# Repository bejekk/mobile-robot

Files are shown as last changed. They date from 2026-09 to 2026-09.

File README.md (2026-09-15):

# Robot mobilny — praca inżynierska

Konstrukcja i oprogramowanie czterokołowego (gąsienicowego) robota mobilnego.
Firmware czasu rzeczywistego na **STM32H755**, sterowanie z **ROS 2 Humble** na Jetson Nano, płyta główna w **KiCad** oraz modele mechaniczne przekładni i obudowy.

Autor: **Błażej Kruszka**, Uniwersytet Mikołaja Kopernika w Toruniu, 2025–2026.

## Architektura

```
gamepad  →  ROS 2 (Jetson)  →  UART 115200  →  STM32H755
                 │                                  │
                 └── /telemetry ← prędkości PI ← enkodery DC, PWM, A4988
```

- **STM32 (CM7)** — enkodery, regulatory PI, mostki H (4× DC), silniki krokowe (4× A4988), protokół UART.
- **ROS 2** — odczyt pada, mostek szeregowy, logger telemetrii.
- **PCB** — płyta główna pod Nucleo-H755, 8 kanałów wykonawczych i interfejsy czujników.

## Struktura repozytorium

| Katalog | Zawartość |
| --- | --- |
| `firmware/` | Projekt STM32CubeIDE (dual-core STM32H755ZITX), bez artefaktów kompilacji |
| `ros2_ws/` | Pakiet `robot_control` + Dockerfile |
| `pcb/` | KiCad (schemat, PCB, Gerber) |
| `mechanical/` | Modele STL i archiwum Fusion 360 |
| `control/` | Skrypt MATLAB do identyfikacji regulatorów PI |
| `docs/` | Praca, prezentacja, opis protokołu UART |

Nie ma tu notatek roboczych, dumpów CubeIDE, kopii zapasowych KiCad, filmów ani cudzych prac.

## Firmware (STM32)

Otwórz folder `firmware/` w STM32CubeIDE (projekt dual-core nadal nazywa się `jakie_wyjscia` — tak zapisał CubeMX). Zbuduj konfigurację **CM7 Debug** oraz CM4, jeśli boot dual-core ma zostać zachowany.

Aplikacja użytkownika:

- `firmware/CM7/Core/Src/PI.c` — pomiar prędkości z enkodera, filtr i regulator PI z rampą oraz anti-windup
- `firmware/CM7/Core/Src/motor_control.c` — PWM + kierunek mostka H, sleep/dir silników krokowych
- `firmware/CM7/Core/Src/main.c` — parser UART, pętla 10 ms, telemetria

Po resecie STM32 czeka na komendę `ready` (buzzer), dopiero potem przyjmuje zadawanie prędkości i krokowych.

## ROS 2

Wymagania: ROS 2 Humble, `python3-serial`, pakiet `inputs`.

```bash
cd ros2_ws
source /opt/ros/humble/setup.bash
colcon build --symlink-install
source install/setup.bash
ros2 launch robot_control robot.launch.py
```

Port UART można zmienić parametrem węzła `stm_bridge`:

```bash
ros2 run robot_control stm_bridge --ros-args -p port:=/dev/ttyACM0 -p baudrate:=115200
```

### Docker (Jetson)

```bash
cd ros2_ws
sudo docker build -t robot_control:humble .
xhost +local:root
sudo docker run -it --rm --network host \
  --runtime nvidia \
  -e DISPLAY=$DISPLAY \
  -v /tmp/.X11-unix:/tmp/.X11-unix \
  --device /dev/input/js0 \
  --device /dev/ttyACM0 \
  robot_control:humble
```

W kontenerze: `source /home/ros_user/ws/install/setup.bash && ros2 launch robot_control robot.launch.py`.

## MATLAB

`control/pi_identification.m` wysyła sekwencję skoków `lspeed`/`rspeed` i rysuje zadanie vs. pomiar dla czterech kół. Ustaw `portName` na swój port (`COM18` w Windows, `/dev/ttyACM0` w Linux).

## PCB

Projekt KiCad 8: `pcb/PCBV2.kicad_pro`. Gerbery do produkcji są w `pcb/gerber/`. Podgląd schematu: `pcb/PCBV2.pdf`.

## Protokół UART

Zobacz [docs/uart.md](docs/uart.md).

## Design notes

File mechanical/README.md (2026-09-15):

# Modele mechaniczne

Eksporty z projektu obudowy i przekładni ślimakowej.

| Plik | Część |
| --- | --- |
| `korpus.stl` | Korpus |
| `pokrywa.stl` | Pokrywa |
| `obudowa.f3z` | Archiwum Fusion 360 |
| `slimak.stl` / `slimacznica.stl` | Przekładnia ślimakowa |
| `ramie.stl` | Ramię |
| `felga_opona.stl` / `felga_gasienica.stl` | Felgi |
| `laczenie_walu1.stl` / `laczenie_wal2.stl` | Łączniki wału |
| `uchwyt_krokowy.stl` | Uchwyt silnika krokowego |

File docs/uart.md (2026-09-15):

# Protokół UART (115200 8N1)

Linie kończy `\n`. STM32 zaczyna wykonywać komendy jezdne dopiero po `ready`.

## Komendy do STM32

| Komenda | Znaczenie |
| --- | --- |
| `ready` | Start pętli regulacji i krótki sygnał buzzera |
| `lspeed=<int>` | Zadana prędkość lewej burty, zakres ok. −100…100 (% max RPM) |
| `rspeed=<int>` | Zadana prędkość prawej burty |
| `forward` / `backward` / `stop` | Kierunek / zatrzymanie silników krokowych (aktywne tylko te, które włączono `*_step`) |
| `fright_step` / `fleft_step` / `bright_step` / `bleft_step` | Przełączenie danego silnika krokowego |
| `P=<int>` / `I=<int>` | Współczynniki PI dla wszystkich czterech kół DC |

## Telemetria ze STM32

CSV, 8 wartości, okres 100 ms:

```
rb_set, rb_meas, rf_set, rf_meas, lb_set, lb_meas, lf_set, lf_meas
```

Jednostka: RPM (zadanie i prędkość przefiltrowana z enkodera).
Mostek ROS dopina na końcu aktualne `lspeed` i `rspeed` wysłane z pada.

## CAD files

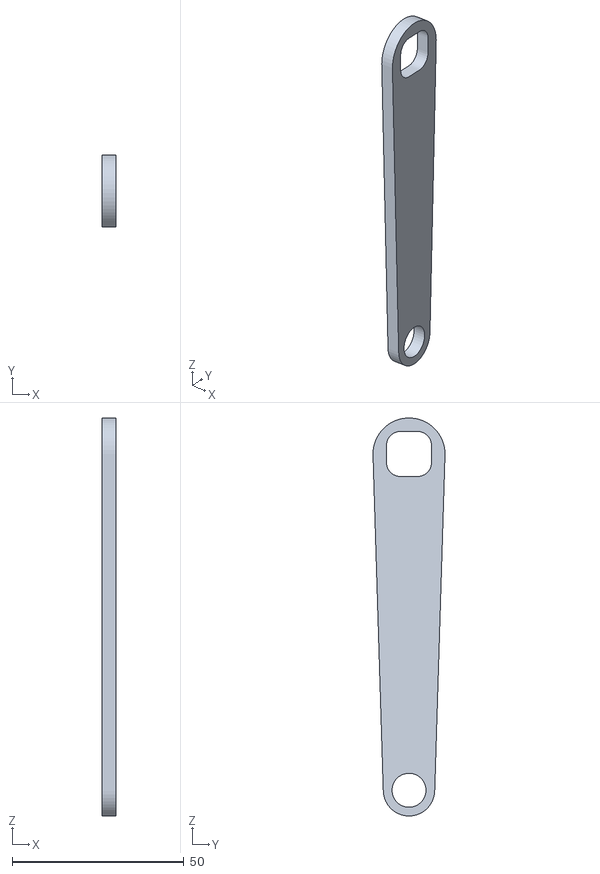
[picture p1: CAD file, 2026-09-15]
mechanical/ramie.stl
4.00 x 21.0 x 116.0

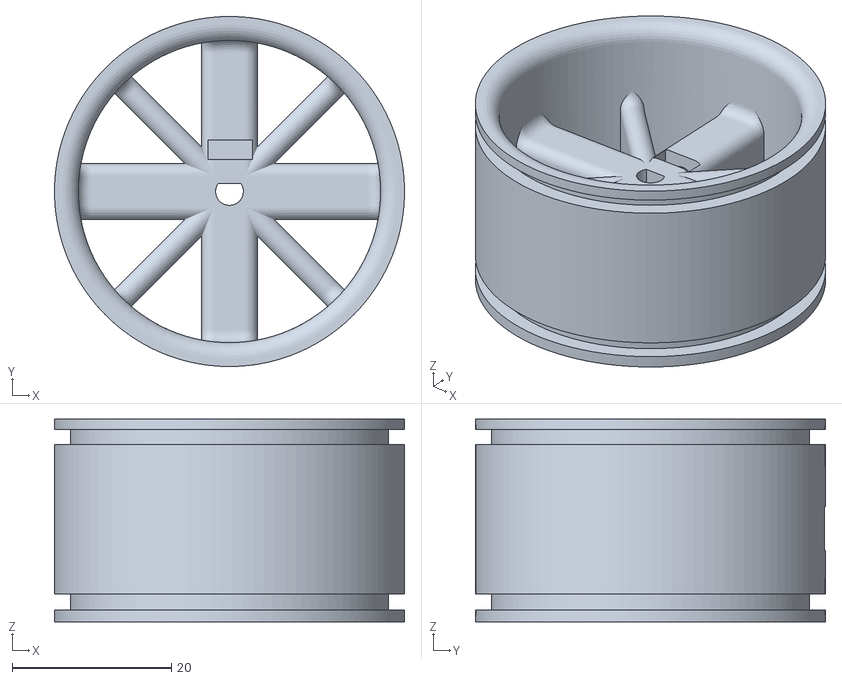
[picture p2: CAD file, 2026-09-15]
mechanical/felga_opona.stl
44.0 x 44.0 x 25.5

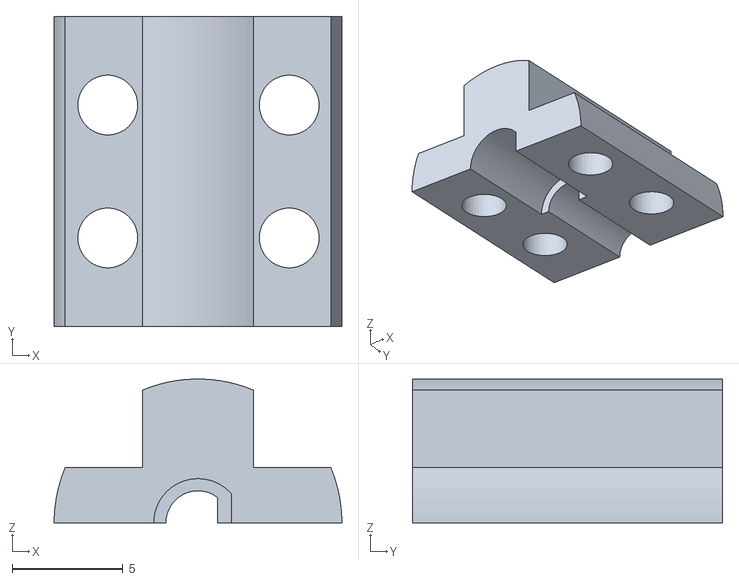
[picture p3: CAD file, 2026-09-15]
mechanical/laczenie_walu1.stl
13.0 x 14.0 x 6.50

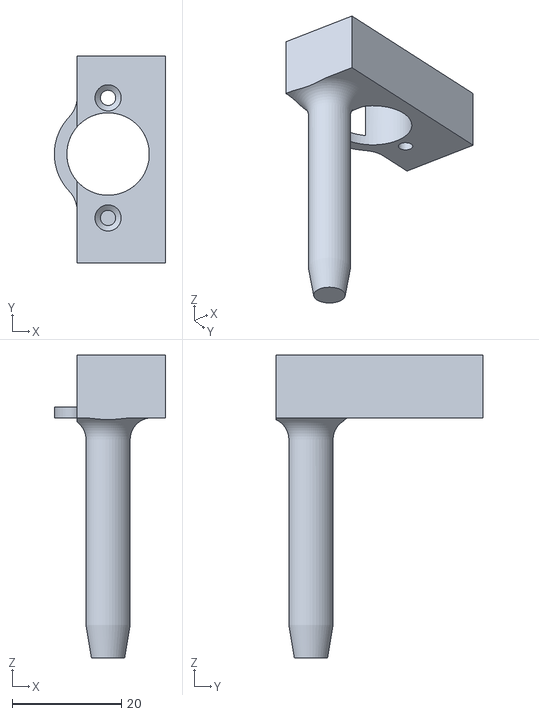
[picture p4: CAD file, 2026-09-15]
mechanical/uchwyt_krokowy.stl
20.4 x 38.0 x 55.5

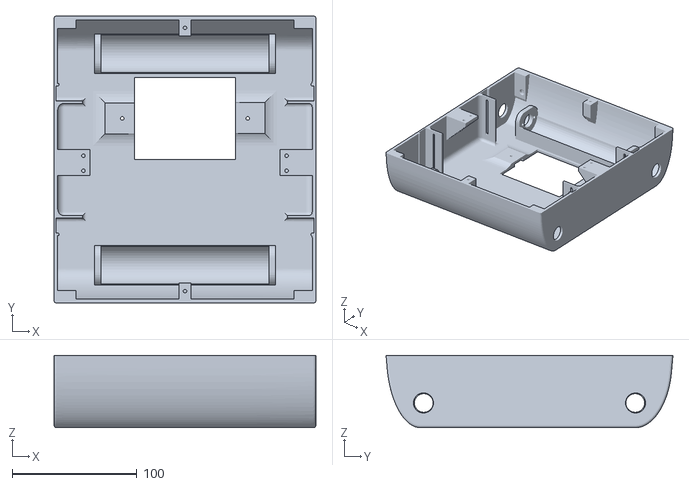
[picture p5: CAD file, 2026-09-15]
mechanical/korpus.stl
210.0 x 230.0 x 58.0

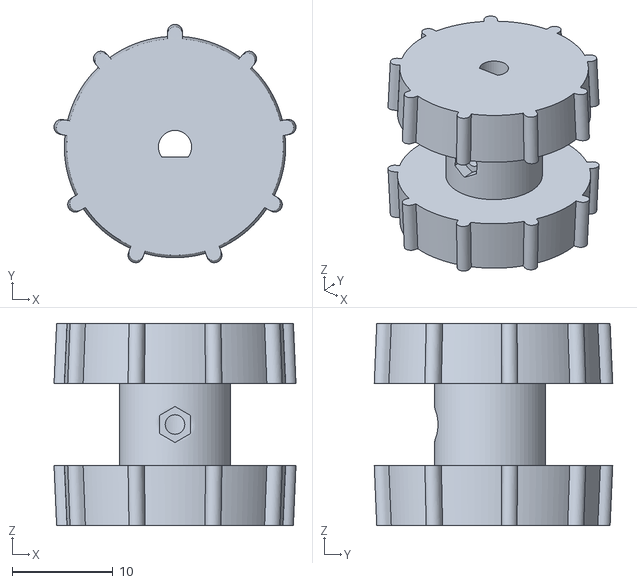
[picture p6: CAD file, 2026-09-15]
mechanical/felga_gasienica.stl
24.0 x 23.7 x 20.1

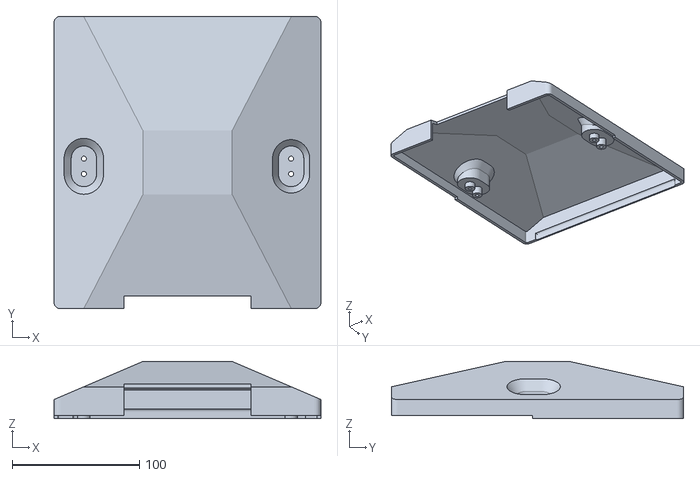
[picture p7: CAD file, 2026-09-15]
mechanical/pokrywa.stl
210.0 x 230.0 x 45.0

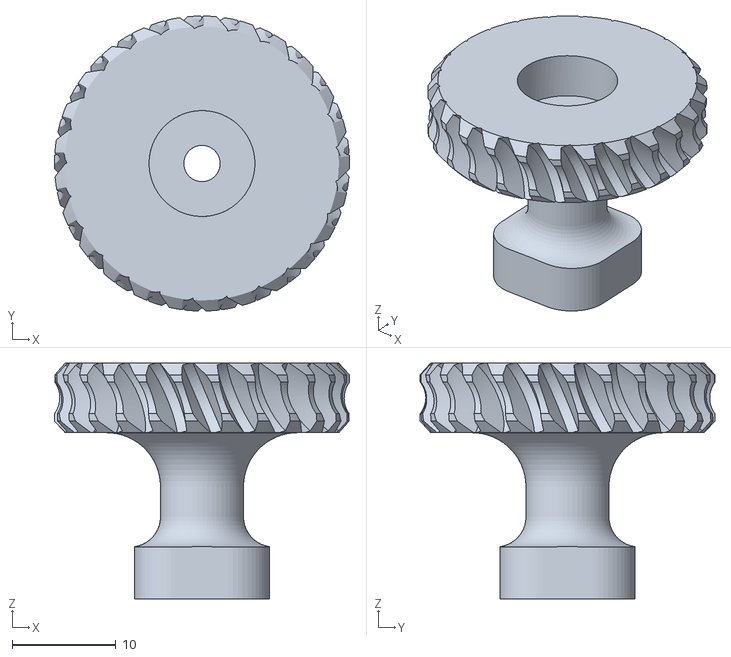
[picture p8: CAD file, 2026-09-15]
mechanical/slimacznica.stl
28.4 x 28.4 x 22.7

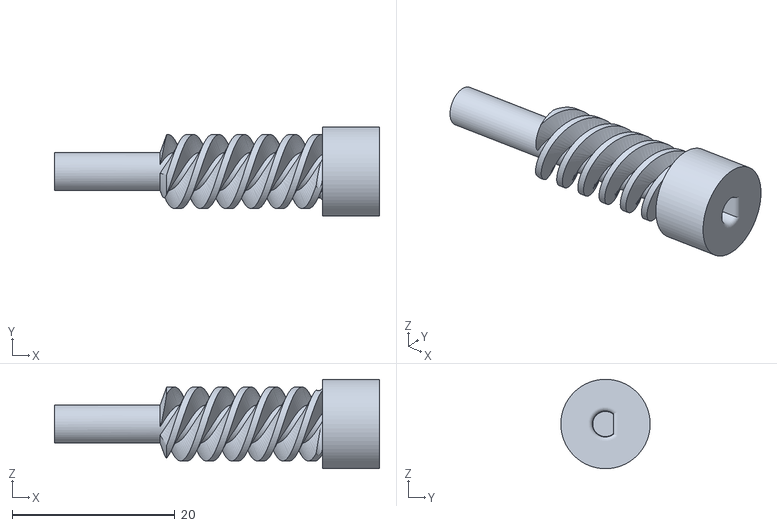
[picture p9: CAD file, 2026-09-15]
mechanical/slimak.stl
40.0 x 11.0 x 11.0

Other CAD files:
mechanical/laczenie_wal2.stl
mechanical/obudowa.f3z

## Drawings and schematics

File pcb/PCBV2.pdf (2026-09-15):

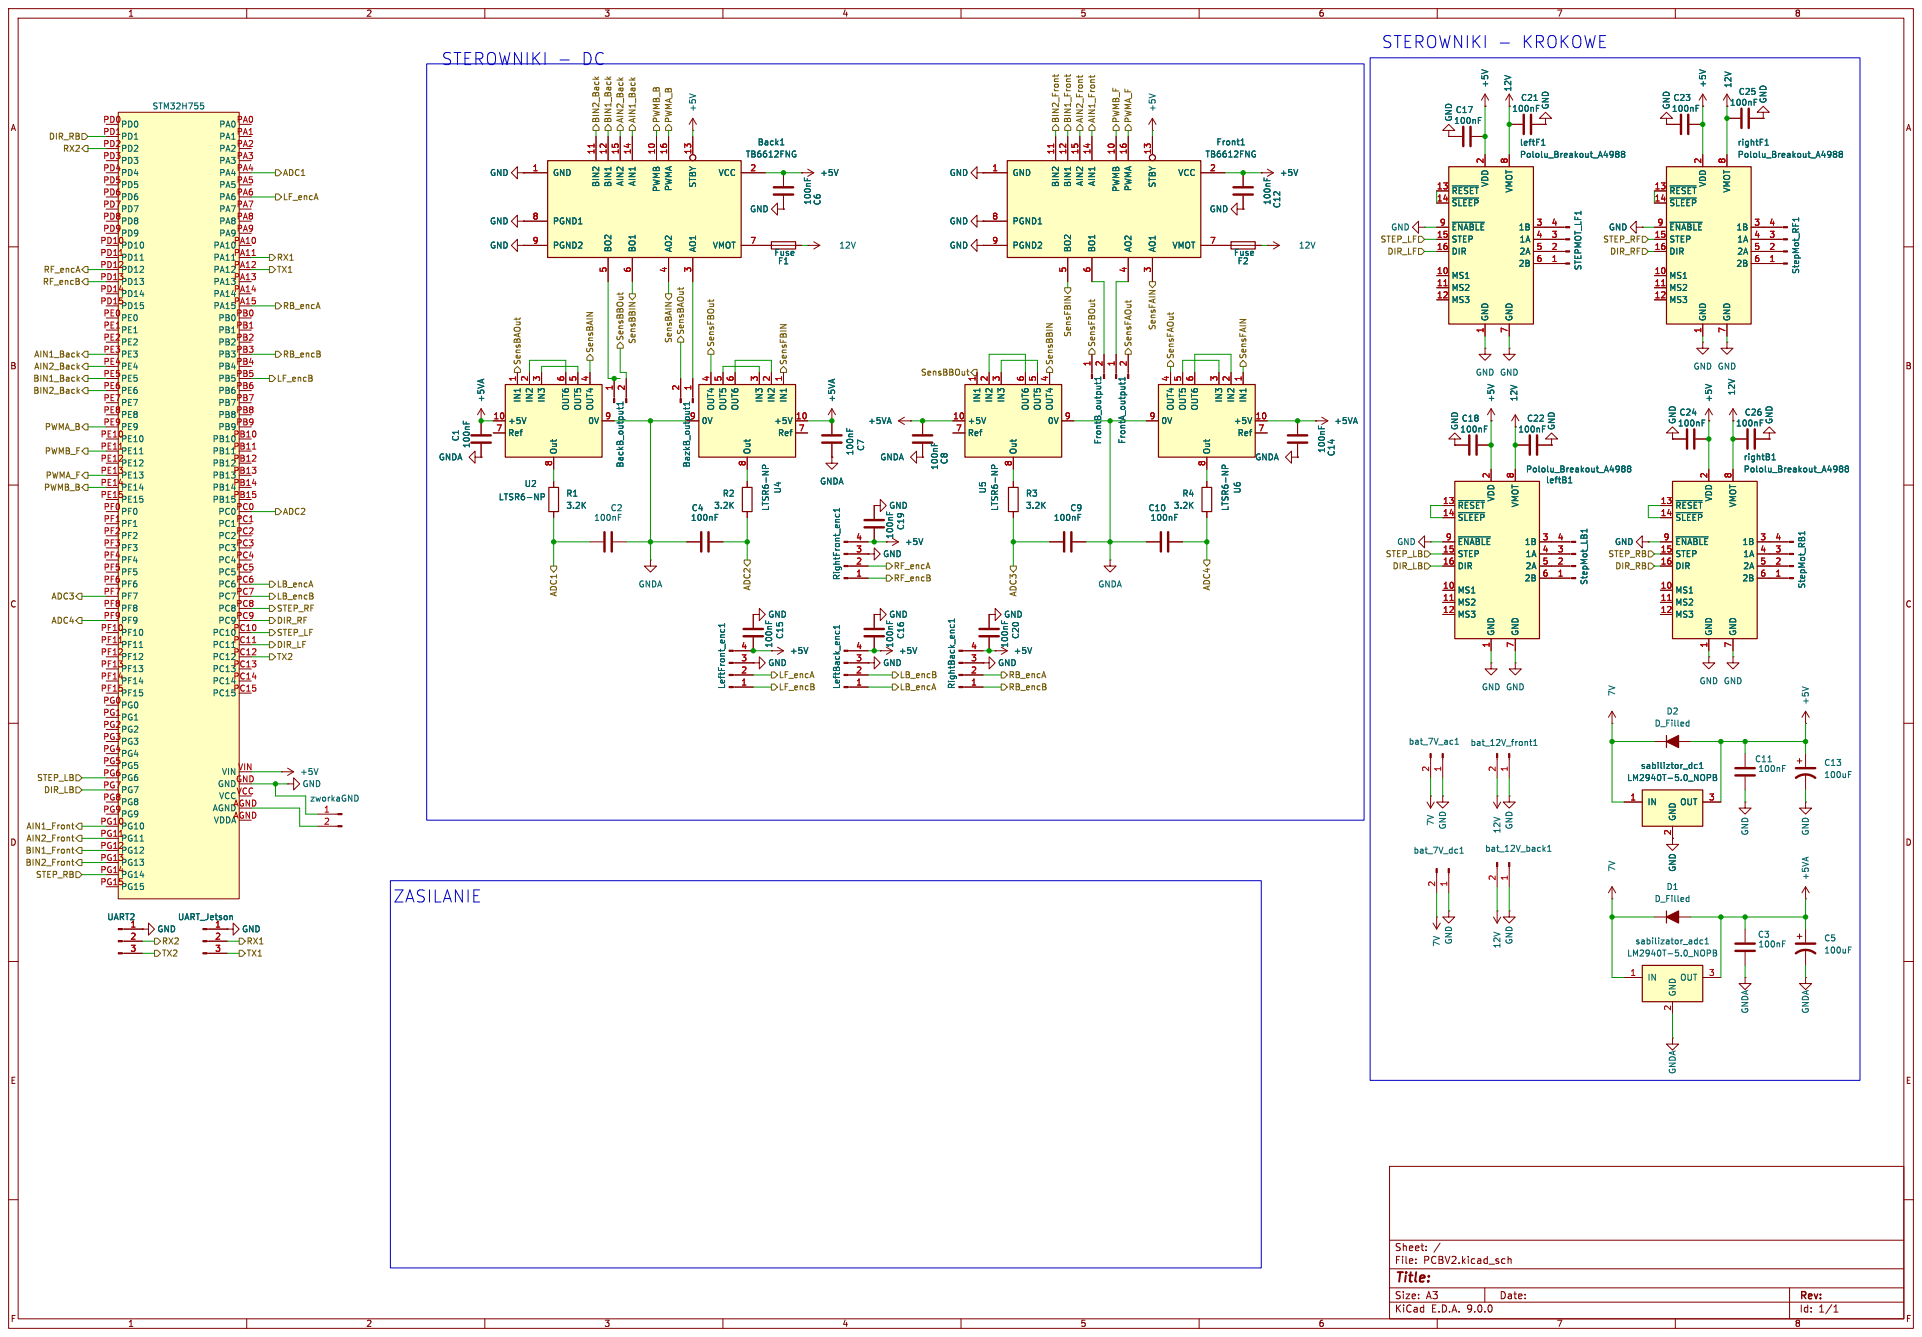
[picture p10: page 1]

4 +5V 10 0V 9 Ref 7 Out 8 Front1 TB6612FNG STBY 13 PWMA 16 PWMB 10 AIN1 14 AIN2 15 BIN1 12 BIN2 11 VCC 2 GND 1 PGND1 8 VMOT 7 PGND2 9 AO1

rightF1 Pololu_Breakout_A4988 ~{RESET} 13 ~{SLEEP} 14 ~{ENABLE} 9 STEP

rightF1 Pololu_Breakout_A4988
~{RESET} 13 ~{SLEEP} 14 ~{ENABLE} 9 STEP

GND GND

4 +5V 10 0V 9 Ref 7 Out 8 U4 LTSR6-NP 7V D2 D_Filled GND GND C7 100nF

rightB1 Pololu_Breakout_A4988 ~{RESET} 13 ~{SLEEP} 14 ~{ENABLE} 9 STEP

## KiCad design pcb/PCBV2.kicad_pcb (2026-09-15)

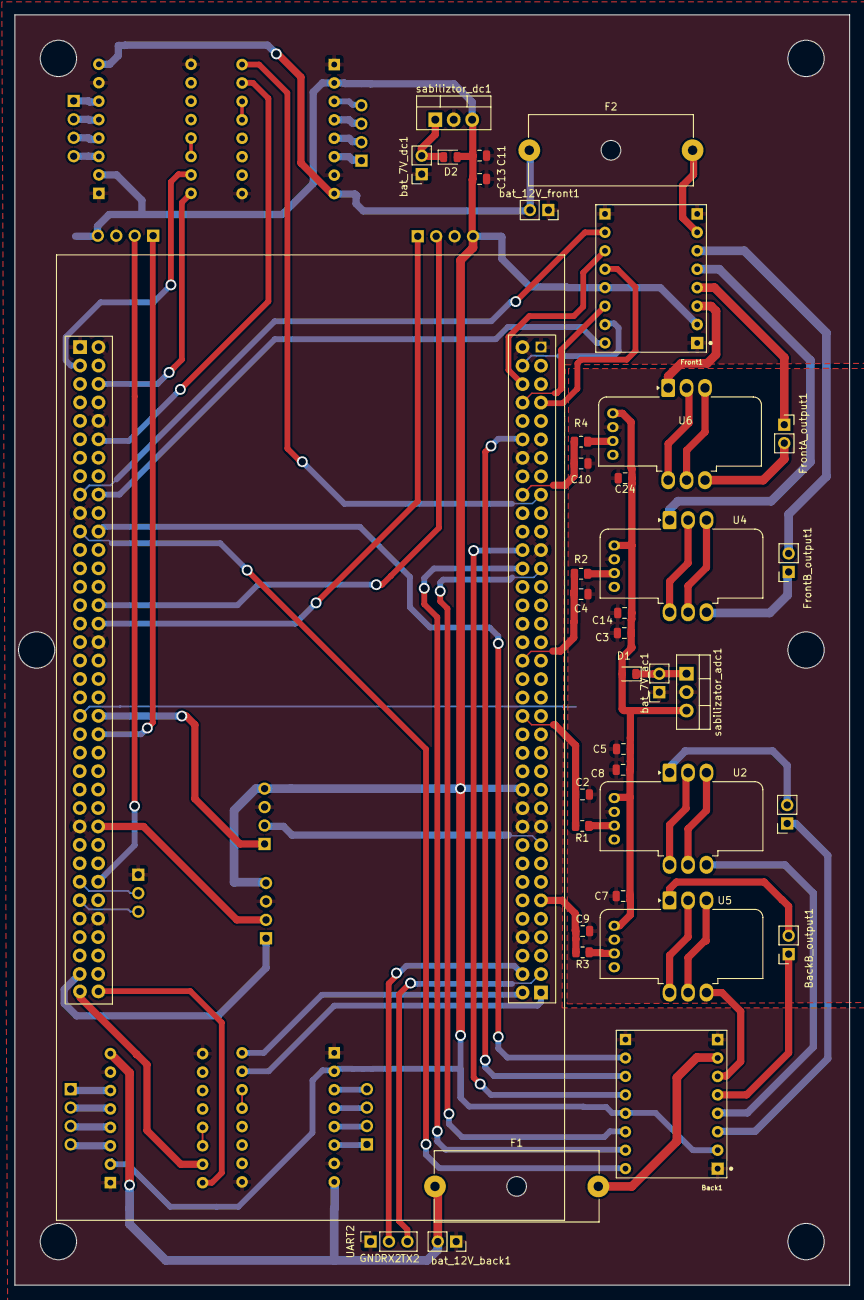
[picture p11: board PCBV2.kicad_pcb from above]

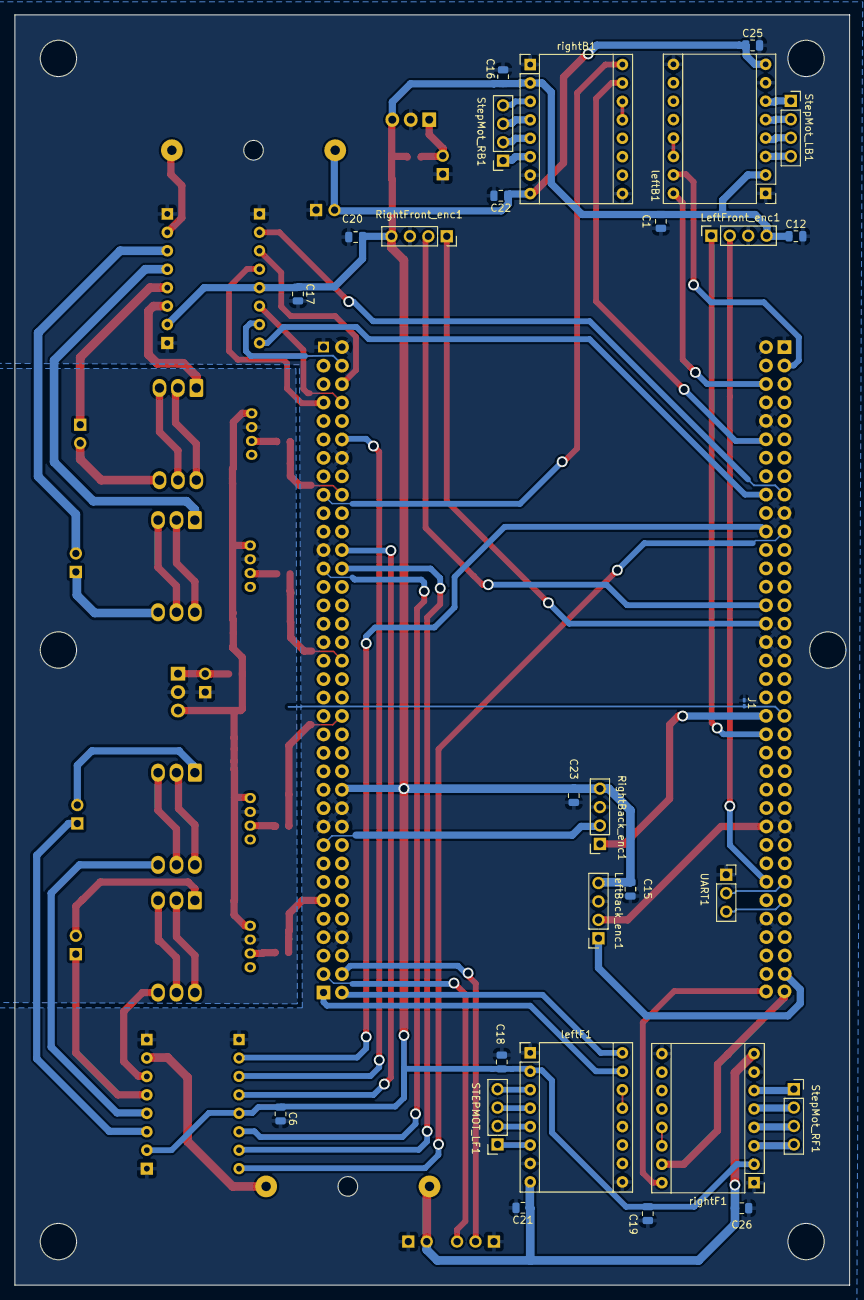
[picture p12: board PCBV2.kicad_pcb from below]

Board: 4 copper layers, 115.0 x 175.0 mm, 66 parts (28 on the bottom side), 89 nets.

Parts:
Back1: TB6612FNG; SHIELD_POLOLU-713
BackB_output1: PinSocket_1x02_P2.54mm_Vertical
BazkB_output1: PinSocket_1x02_P2.54mm_Vertical
C1, C2, C3, C4, C6, C7, C8, C9, C10, C11, C12, C14, C15, C16, C17, C18, C19, C20, C21, C22, C23, C24, C25, C26: 100nF; C_0805_2012Metric
C5, C13: 100uF; C_0805_2012Metric
D1, D2: D_Filled; D_0805_2012Metric
F1, F2: Fuse; Fuseholder_Cylinder-5x20mm_Schurter_0031_8201_Horizontal_Op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
Front1: TB6612FNG; SHIELD_POLOLU-713
FrontA_output1: PinSocket_1x02_P2.54mm_Vertical
FrontB_output1: PinSocket_1x02_P2.54mm_Vertical
J1: zworaGND; R_0201_0603Metric_Pad0.64x0.40mm_HandSolder
LeftBack_enc1: Conn_01x04_Pin; PinSocket_1x04_P2.54mm_Vertical
LeftFront_enc1: Conn_01x04_Pin; PinSocket_1x04_P2.54mm_Vertical
R1, R2, R3, R4: 3.2K; R_0805_2012Metric
RightBack_enc1: Conn_01x04_Pin; PinSocket_1x04_P2.54mm_Vertical
RightFront_enc1: Conn_01x04_Pin; PinSocket_1x04_P2.54mm_Vertical
STEPMOT_LF1: Conn_01x04_Pin; PinSocket_1x04_P2.54mm_Vertical
StepMot_LB1: Conn_01x04_Pin; PinSocket_1x04_P2.54mm_Vertical
StepMot_RB1: Conn_01x04_Pin; PinSocket_1x04_P2.54mm_Vertical
StepMot_RF1: Conn_01x04_Pin; PinSocket_1x04_P2.54mm_Vertical
U1: STM32H755
U2, U4, U5, U6: LTSR6-NP; LEM_LTSR-NP
UART1: UART1; PinSocket_1x03_P2.54mm_Vertical
UART2: UART2; PinSocket_1x03_P2.54mm_Vertical
bat_7V_ac1, bat_7V_dc1, bat_12V_back1, bat_12V_front1: PinSocket_1x02_P2.54mm_Vertical
leftB1: Pololu_Breakout_A4988; Pololu_Breakout-16_15.2x20.3mm
leftF1: Pololu_Breakout_A4988; Pololu_Breakout-16_15.2x20.3mm
rightB1: Pololu_Breakout_A4988; Pololu_Breakout-16_15.2x20.3mm
rightF1: Pololu_Breakout_A4988; Pololu_Breakout-16_15.2x20.3mm
sabilizator_adc1: LM2940T-5.0_NOPB; TO-220-3_Vertical
sabiliztor_dc1: LM2940T-5.0_NOPB; TO-220-3_Vertical

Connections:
7V: D1.1 (K), D2.1 (K), bat_7V_ac1.2, bat_7V_dc1.2, sabilizator_adc1.1 (IN), sabiliztor_dc1.1 (IN)
12V: C21.1, C22.1, C25.1, C26.1, F1.1, F2.1, bat_12V_back1.2, bat_12V_front1.2, leftB1.8 (VMOT), leftF1.8 (VMOT), rightB1.8 (VMOT), rightF1.8 (VMOT)
+5V: Back1.2 (VCC), Back1.13 (STBY), C1.1, C6.1, C11.2, C12.1, C13.1, C15.1, C16.1, C17.1, C18.1, C19.1, C20.1, C23.1, D2.2 (A), Front1.2 (VCC), Front1.13 (STBY), LeftBack_enc1.4, LeftFront_enc1.4, RightBack_enc1.4, RightFront_enc1.4, U1.VIN, leftB1.2 (VDD), leftF1.2 (VDD), rightB1.2 (VDD), rightF1.2 (VDD), sabiliztor_dc1.3 (OUT)
+5VA: C3.2, C5.1, C7.1, C8.1, C14.1, C24.1, D1.2 (A), U2.10 (+5V), U4.10 (+5V), U5.10 (+5V), U6.10 (+5V), sabilizator_adc1.3 (OUT)
/ADC1: C2.1, R1.2, U1.PA4
/ADC2: C4.2, R2.2, U1.PC0
/ADC3: C9.1, R3.2, U1.PF7
/ADC4: C10.2, R4.2, U1.PF9
/AIN1_Back: Back1.14 (AIN1), U1.PE3
/AIN1_Front: Front1.14 (AIN1), U1.PG10
/AIN2_Back: Back1.15 (AIN2), U1.PE4
/AIN2_Front: Front1.15 (AIN2), U1.PG11
/BIN1_Back: Back1.12 (BIN1), U1.PE5
/BIN1_Front: Front1.12 (BIN1), U1.PG12
/BIN2_Back: Back1.11 (BIN2), U1.PE6
/BIN2_Front: Front1.11 (BIN2), U1.PG13
/DIR_LB: U1.PG7, leftB1.16 (DIR)
/DIR_LF: U1.PC11, leftF1.16 (DIR)
/DIR_RB: U1.PD1, rightB1.16 (DIR)
/DIR_RF: U1.PC9, rightF1.16 (DIR)
/LB_encA: LeftBack_enc1.1, U1.PC6
/LB_encB: LeftBack_enc1.2, U1.PC7
/LF_encA: LeftFront_enc1.2, U1.PA6
/LF_encB: LeftFront_enc1.1, U1.PB5
/PWMA_B: Back1.16 (PWMA), U1.PE9
/PWMA_F: Front1.16 (PWMA), U1.PE13
/PWMB_B: Back1.10 (PWMB), U1.PE14
/PWMB_F: Front1.10 (PWMB), U1.PE11
/RB_encA: RightBack_enc1.2, U1.PA15
/RB_encB: RightBack_enc1.1, U1.PB3
/RF_encA: RightFront_enc1.2, U1.PD12
/RF_encB: RightFront_enc1.1, U1.PD13
/RX1: U1.PA11, UART1.2
/RX2: U1.PD2, UART2.2
/STEP_LB: U1.PG6, leftB1.15 (STEP)
/STEP_LF: U1.PC10, leftF1.15 (STEP)
/STEP_RB: U1.PG14, rightB1.15 (STEP)
/STEP_RF: U1.PC8, rightF1.15 (STEP)
/SensBAIN: Back1.4 (AO2), U2.4 (OUT4)
/SensBAOut: BazkB_output1.2, U2.1 (IN1)
/SensBBIN: Back1.6 (BO1), U5.4 (OUT4)
/SensBBOut: BackB_output1.2, U5.1 (IN1)
/SensFAIN: Front1.3 (AO1), U6.1 (IN1)
/SensFAOut: FrontA_output1.2, U6.4 (OUT4)
/SensFBIN: Front1.5 (BO2), U4.1 (IN1)
/SensFBOut: FrontB_output1.1, U4.4 (OUT4)
/TX1: U1.PA12, UART1.3
/TX2: U1.PC12, UART2.3
GND: Back1.1 (GND), Back1.8 (PGND1), Back1.9 (PGND2), C1.2, C6.2, C11.1, C12.2, C13.2, C15.2, C16.2, C17.2, C18.2, C19.2, C20.2, C21.2, C22.2, C23.2, C25.2, C26.2, Front1.1 (GND), Front1.8 (PGND1), Front1.9 (PGND2), J1.1, LeftBack_enc1.3, LeftFront_enc1.3, RightBack_enc1.3, RightFront_enc1.3, U1.GND, UART1.1, UART2.1, bat_7V_dc1.1, bat_12V_back1.1, bat_12V_front1.1, leftB1.1 (GND), leftB1.7 (GND), leftB1.9 (~ENABLE), leftF1.1 (GND), leftF1.7 (GND), leftF1.9 (~ENABLE), rightB1.1 (GND), rightB1.7 (GND), rightB1.9 (~ENABLE), rightF1.1 (GND), rightF1.7 (GND), rightF1.9 (~ENABLE), sabiliztor_dc1.2 (GND)
GNDA: C2.2, C3.1, C4.1, C5.2, C7.2, C8.2, C9.2, C10.1, C14.2, C24.2, U2.9 (0V), U4.9 (0V), U5.9 (0V), U6.9 (0V), bat_7V_ac1.1, sabilizator_adc1.2 (GND)
unnamed: Back1.3 (AO1), BazkB_output1.1
unnamed: Back1.5 (BO2), BackB_output1.1
unnamed: Back1.7 (VMOT), F1.2
unnamed: Front1.4 (AO2), FrontA_output1.1
unnamed: Front1.6 (BO1), FrontB_output1.2
unnamed: F2.2, Front1.7 (VMOT)
unnamed: J1.2, U1.AGND
unnamed: STEPMOT_LF1.1, leftF1.6 (2B)
unnamed: STEPMOT_LF1.2, leftF1.5 (2A)
unnamed: STEPMOT_LF1.3, leftF1.4 (1A)
unnamed: STEPMOT_LF1.4, leftF1.3 (1B)
unnamed: StepMot_LB1.1, leftB1.6 (2B)
unnamed: StepMot_LB1.2, leftB1.5 (2A)
unnamed: StepMot_LB1.3, leftB1.4 (1A)
unnamed: StepMot_LB1.4, leftB1.3 (1B)
unnamed: StepMot_RB1.1, rightB1.6 (2B)
unnamed: StepMot_RB1.2, rightB1.5 (2A)
unnamed: StepMot_RB1.3, rightB1.4 (1A)
unnamed: StepMot_RB1.4, rightB1.3 (1B)
unnamed: StepMot_RF1.1, rightF1.6 (2B)
unnamed: StepMot_RF1.2, rightF1.5 (2A)
unnamed: StepMot_RF1.3, rightF1.4 (1A)
unnamed: StepMot_RF1.4, rightF1.3 (1B)
unnamed: U2.2 (IN2), U2.6 (OUT6)
unnamed: U2.3 (IN3), U2.5 (OUT5)
unnamed: R1.1, U2.8 (Out)
unnamed: U4.2 (IN2), U4.6 (OUT6)
unnamed: U4.3 (IN3), U4.5 (OUT5)
unnamed: R2.1, U4.8 (Out)
unnamed: U5.2 (IN2), U5.6 (OUT6)
unnamed: U5.3 (IN3), U5.5 (OUT5)
unnamed: R3.1, U5.8 (Out)
unnamed: U6.2 (IN2), U6.6 (OUT6)
unnamed: U6.3 (IN3), U6.5 (OUT5)
unnamed: R4.1, U6.8 (Out)
unnamed: leftB1.13 (~RESET), leftB1.14 (~SLEEP)
unnamed: leftF1.13 (~RESET), leftF1.14 (~SLEEP)
unnamed: rightB1.13 (~RESET), rightB1.14 (~SLEEP)
unnamed: rightF1.13 (~RESET), rightF1.14 (~SLEEP)

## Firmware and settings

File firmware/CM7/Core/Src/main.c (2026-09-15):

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
/* Includes ------------------------------------------------------------------*/
#include "main.h"
#include "lwip.h"

/* USER CODE BEGIN Includes */
#include "motor_control.h"
#include "PI.h"
#include <stdbool.h>
#include <stdio.h>
#include <string.h>
#include <math.h>
/* USER CODE END Includes */

/* USER CODE BEGIN PD */

#ifndef HSEM_ID_0
#define HSEM_ID_0 (0U) /* HW semaphore 0*/
#endif

/* USER CODE END PD */

ADC_HandleTypeDef hadc1;
ADC_HandleTypeDef hadc3;

I2C_HandleTypeDef hi2c1;

SPI_HandleTypeDef hspi1;

TIM_HandleTypeDef htim1;
TIM_HandleTypeDef htim2;
TIM_HandleTypeDef htim3;
TIM_HandleTypeDef htim4;
TIM_HandleTypeDef htim6;
TIM_HandleTypeDef htim7;
TIM_HandleTypeDef htim8;
TIM_HandleTypeDef htim13;
TIM_HandleTypeDef htim14;
TIM_HandleTypeDef htim15;

UART_HandleTypeDef huart4;
UART_HandleTypeDef huart5;
UART_HandleTypeDef huart7;
UART_HandleTypeDef huart3;

/* USER CODE BEGIN PV */
uint8_t rx_byte;		/* bajt z USART3 (przerwanie RX) */
char rx_buffer[50];		/* składana komenda UART aż do '\n' */
uint8_t rx_index = 0;

/* Flagi silników krokowych (1 = dany A4988 ma być aktywny przy forward/backward). */
volatile uint8_t fright = 0, fleft = 0, bright = 0, bleft = 0, stop = 0, forward = 0, backward = 0;
volatile int Rvel = 0, Lvel = 0;	/* zadanie z UART: lspeed/rspeed w % */
volatile uint16_t steps_fright = 0, steps_bright = 0, steps_fleft = 0, steps_bleft = 0;

DC_str right_front, left_front, right_back, left_back;

int Kp = 14;
int Ki = 30;
int32_t MAX_SPEED_RPM = 200;

float P = 0;
volatile uint32_t raw_adc_val1 = 0;
volatile uint32_t raw_adc_val3 = 0;
volatile float PomiarADC;	/* prąd z przetwornika LTS (skalowanie w pętli głównej) */

/* USER CODE END PV */

void SystemClock_Config(void);
void PeriphCommonClock_Config(void);
static void MPU_Config(void);
static void MX_GPIO_Init(void);
static void MX_ADC1_Init(void);
static void MX_ADC3_Init(void);
static void MX_SPI1_Init(void);
static void MX_TIM1_Init(void);
static void MX_TIM2_Init(void);
static void MX_TIM3_Init(void);
static void MX_TIM4_Init(void);
static void MX_TIM8_Init(void);
static void MX_UART4_Init(void);
static void MX_TIM6_Init(void);
static void MX_TIM7_Init(void);
static void MX_UART7_Init(void);
static void MX_I2C1_Init(void);
static void MX_TIM13_Init(void);
static void MX_TIM14_Init(void);
static void MX_UART5_Init(void);
static void MX_USART3_UART_Init(void);
static void MX_TIM15_Init(void);
/* USER CODE BEGIN 0 */
void DC_str_init(DC_str *m, TIM_HandleTypeDef *tim, int8_t d, int32_t max)
{
	m->timer = tim;
	m->pulse_count = 0;
	m->actual_speed = 0;
	m->d = d;			/* znak enkodera — lewa/prawa oś mogą być lustrzane */
	m->max_speed = max;
	m->target_speed = 0;
	m->error_sum = 0;
	m->last_output = 0;
	m->current_setpoint = 0.0f;
	m->alpha = 0.1f;		/* silne wygładzenie na starcie */
	m->filtered_speed = 0.0f;
}

/* Telemetria: zadanie i pomiar [RPM] dla 4 kół, kolejność RB, RF, LB, LF. */
void UART_SendSpeeds(void)
{
	char msg[100];
	int len = sprintf(msg, "%ld, %ld, %ld, %ld, %ld, %ld, %ld, %ld\r\n",
			  (long)right_back.target_speed,
			  (long)right_back.filtered_speed,
			  (long)right_front.target_speed,
			  (long)right_front.filtered_speed,
			  (long)left_back.target_speed,
			  (long)left_back.filtered_speed,
			  (long)left_front.target_speed,
			  (long)left_front.filtered_speed);
	HAL_UART_Transmit(&huart3, (uint8_t *)msg, len, 10);	/* UART3 → Jetson / PC */
}

static int buzzer_tick = 0;

void HAL_TIM_PeriodElapsedCallback(TIM_HandleTypeDef *htim)
{
	/* TIM13: pętla 10 ms — buzzer po "ready", PI i PWM kół DC. */
	if (htim->Instance == TIM13) {
		/* Krótki impuls buzzera (~0,5 s) po starcie pętli regulacji. */
		if (buzzer_tick < 50) {
			HAL_GPIO_WritePin(GPIOD, GPIO_PIN_6, GPIO_PIN_SET);
			buzzer_tick++;
		} else if (buzzer_tick < 60) {
			HAL_GPIO_WritePin(GPIOD, GPIO_PIN_6, GPIO_PIN_RESET);
			buzzer_tick = 100;
		}

		DC_update_speed(&right_front);
		DC_update_speed(&left_front);
		DC_update_speed(&right_back);
		DC_update_speed(&left_back);

		static uint8_t uart_div = 0;
		if (++uart_div >= 10) {		/* 10 × 10 ms = 100 ms telemetrii */
			UART_SendSpeeds();
			uart_div = 0;
		}

		int16_t out_rf = PI_Compute(&right_front);
		int16_t out_rb = PI_Compute(&right_back);
		int16_t out_lf = PI_Compute(&left_front);
		int16_t out_lb = PI_Compute(&left_back);

		/* Skalowanie wyjścia PI do zakresu PWM mostka (0…100). */
		fright_motor(((float)out_rf / right_front.max_speed) * 100);
		bright_motor(((float)out_rb / right_back.max_speed) * 100);
		fleft_motor(((float)out_lf / left_front.max_speed) * 100);
		bleft_motor(((float)out_lb / left_back.max_speed) * 100);
	}

	/* TIM6/7/14/15: impuls STEP na A4988 + zliczanie kroków. */
	if (htim->Instance == TIM6) {
		HAL_GPIO_TogglePin(GPIOG, GPIO_PIN_6);
		if (forward) {
			steps_bleft++;
		} else {
			steps_bleft--;
		}
	}
	if (htim->Instance == TIM7) {
		HAL_GPIO_TogglePin(GPIOG, GPIO_PIN_14);
		if (forward) {
			steps_bright++;
		} else {
			steps_bright--;
		}
	}
	if (htim->Instance == TIM15) {
		HAL_GPIO_TogglePin(GPIOC, GPIO_PIN_8);
		if (forward) {
			steps_fright++;
		} else {
			steps_fright--;
		}
	}
	if (htim->Instance == TIM14) {
		HAL_GPIO_TogglePin(GPIOC, GPIO_PIN_10);
		if (forward) {
			steps_fleft++;
		} else {
			steps_fleft--;
		}
	}
}

void parse_command(char command[50])
{
	static bool ready = false;

	/* Bez "ready" pętla PI nie startuje — zabezpieczenie przed jazdą tuż po resecie USB. */
	if (strcmp(command, "ready") == 0) {
		HAL_TIM_Base_Start_IT(&htim13);
		ready = true;
	}

	if (ready) {
		/* *_step przełącza, czy dany silnik krokowy ma jechać przy forward/backward. */
		if (strcmp(command, "fright_step") == 0) {
			fright = !fright;
		} else if (strcmp(command, "fleft_step") == 0) {
			fleft = !fleft;
		} else if (strcmp(command, "bleft_step") == 0) {
			bleft = !bleft;
		} else if (strcmp(command, "bright_step") == 0) {
			bright = !bright;
		}

		if (strcmp(command, "forward") == 0) {
			stepper_control(bleft, GPIOG, GPIO_PIN_7, 1, &htim6, GPIOG, GPIO_PIN_8);
			stepper_control(bright, GPIOD, GPIO_PIN_1, 1, &htim7, GPIOD, GPIO_PIN_10);
			stepper_control(fright, GPIOC, GPIO_PIN_9, 1, &htim15, GPIOB, GPIO_PIN_8);
			stepper_control(fleft, GPIOC, GPIO_PIN_11, 1, &htim14, GPIOB, GPIO_PIN_9);
		} else if (strcmp(command, "backward") == 0) {
			stepper_control(bleft, GPIOG, GPIO_PIN_7, 0, &htim6, GPIOG, GPIO_PIN_8);
			stepper_control(bright, GPIOD, GPIO_PIN_1, 0, &htim7, GPIOD, GPIO_PIN_10);
			stepper_control(fright, GPIOC, GPIO_PIN_9, 0, &htim15, GPIOB, GPIO_PIN_8);
			stepper_control(fleft, GPIOC, GPIO_PIN_11, 0, &htim14, GPIOB, GPIO_PIN_9);
		} else if (strcmp(command, "stop") == 0) {
			stepper_control(0, GPIOG, GPIO_PIN_7, 0, &htim6, GPIOG, GPIO_PIN_8);
			stepper_control(0, GPIOD, GPIO_PIN_1, 0, &htim7, GPIOD, GPIO_PIN_10);
			stepper_control(0, GPIOC, GPIO_PIN_9, 0, &htim15, GPIOB, GPIO_PIN_8);
			stepper_control(0, GPIOC, GPIO_PIN_11, 0, &htim14, GPIOB, GPIO_PIN_9);
		}

		/* lspeed/rspeed w % max RPM, ta sama wartość na koła przednie i tylne danej burty. */
		if (strncmp(command, "lspeed=", 7) == 0) {
			if (sscanf(command, "lspeed=%d", &Lvel) == 1) {
				left_front.target_speed = (left_front.max_speed / 100) * Lvel;
				left_back.target_speed = (left_back.max_speed / 100) * Lvel;
			}
		}
		if (strncmp(command, "rspeed=", 7) == 0) {
			if (sscanf(command, "rspeed=%d", &Rvel) == 1) {
				right_front.target_speed = (right_front.max_speed / 100) * Rvel;
				right_back.target_speed = (right_back.max_speed / 100) * Rvel;
			}
		}
	}

	/* P= i I= działają też przed ready — wygodne przy strojeniu z MATLABa. */
	if (strncmp(command, "P=", 2) == 0) {
		if (sscanf(command, "P=%d", &Kp) == 1) {
			right_front.Kp = (float)Kp;
			left_front.Kp = (float)Kp;
			right_back.Kp = (float)Kp;
			left_back.Kp = (float)Kp;
		}
	}
	if (strncmp(command, "I=", 2) == 0) {
		if (sscanf(command, "I=%d", &Ki) == 1) {
			right_front.Ki = (float)Ki;
			left_front.Ki = (float)Ki;
			right_back.Ki = (float)Ki;
			left_back.Ki = (float)Ki;
		}
	}
}

/* USER CODE END 0 */



/**
  * @brief  The application entry point.
  * @retval int
  */
int main(void)
{

/* USER CODE BEGIN Boot_Mode_Sequence_0 */
  int32_t timeout;
/* USER CODE END Boot_Mode_Sequence_0 */

  /* MPU Configuration--------------------------------------------------------*/
  MPU_Config();

/* USER CODE BEGIN Boot_Mode_Sequence_1 */
  /* Wait until CPU2 boots and enters in stop mode or timeout*/

/* USER CODE END Boot_Mode_Sequence_1 */
  /* MCU Configuration--------------------------------------------------------*/

  /* Reset of all peripherals, Initializes the Flash interface and the Systick. */
  HAL_Init();

  /* Configure the system clock */
  SystemClock_Config();

  /* Configure the peripherals common clocks */
  PeriphCommonClock_Config();
/* USER CODE BEGIN Boot_Mode_Sequence_2 */
/* When system initialization is finished, Cortex-M7 will release Cortex-M4 by means of
HSEM notification */
/*HW semaphore Clock enable*/
__HAL_RCC_HSEM_CLK_ENABLE();
/*Take HSEM */
HAL_HSEM_FastTake(HSEM_ID_0);
/*Release HSEM in order to notify the CPU2(CM4)*/
HAL_HSEM_Release(HSEM_ID_0,0);
/* wait until CPU2 wakes up from stop mode */
timeout = 0xFFFF;
while((__HAL_RCC_GET_FLAG(RCC_FLAG_D2CKRDY) == RESET) && (timeout-- > 0));
if ( timeout < 0 )
{
Error_Handler();
}
/* USER CODE END Boot_Mode_Sequence_2 */

  /* Initialize all configured peripherals */
  MX_GPIO_Init();
  MX_ADC1_Init();
  MX_ADC3_Init();
  MX_SPI1_Init();
  MX_TIM1_Init();
  MX_TIM2_Init();
  MX_TIM3_Init();
  MX_TIM4_Init();
  MX_TIM8_Init();
  MX_UART4_Init();
  MX_LWIP_Init();
  MX_TIM6_Init();
  MX_TIM7_Init();
  MX_UART7_Init();
  MX_I2C1_Init();
  MX_TIM13_Init();
  MX_TIM14_Init();
  MX_UART5_Init();
  MX_USART3_UART_Init();
  MX_TIM15_Init();
  /* USER CODE BEGIN 2 */
  /* Osobne Kp/Ki na koło — wartości z identyfikacji (MATLAB). */
  right_front.Kp = 13; right_front.Ki =15;
  left_front.Kp  = 12; left_front.Ki = 16;
  right_back.Kp  = 10; right_back.Ki = 17;
  left_back.Kp   = 12; left_back.Ki = 16;

  /* d = -1 tam, gdzie enkoder liczy w przeciwną stronę niż zadany ruch. */
  DC_str_init(&right_front, &htim3, -1, 350);
  DC_str_init(&left_front, &htim8, -1, 350);
  DC_str_init(&right_back, &htim4, -1, 350);
  DC_str_init(&left_back, &htim2, 1, 350);

  HAL_TIM_Encoder_Start(&htim2, TIM_CHANNEL_ALL);
  HAL_TIM_Encoder_Start(&htim3, TIM_CHANNEL_ALL);
  HAL_TIM_Encoder_Start(&htim4, TIM_CHANNEL_ALL);
  HAL_TIM_Encoder_Start(&htim8, TIM_CHANNEL_ALL);

  HAL_ADCEx_Calibration_Start(&hadc1, ADC_CALIB_OFFSET, ADC_SINGLE_ENDED);
  HAL_ADCEx_Calibration_Start(&hadc3, ADC_CALIB_OFFSET, ADC_SINGLE_ENDED);

  HAL_ADC_Start(&hadc1);
  HAL_UART_Receive_IT(&huart3, &rx_byte, 1);	/* start odbioru komend z ROS */
  /* USER CODE END 2 */

  /* Infinite loop */
  /* USER CODE BEGIN WHILE */
  while (1)
  {
	  if (HAL_ADC_PollForConversion(&hadc1, 10) == HAL_OK) {
	  							/* LTS-6-NP: 16-bit ADC → prąd [A] (2 / 0.625 ze wzmocnienia). */
	  							PomiarADC = ((float)HAL_ADC_GetValue(&hadc1)/65536*3.3)*2/0.625;
	  							HAL_ADC_Start(&hadc1);
	  						}
    /* USER CODE END WHILE */

    /* USER CODE BEGIN 3 */
  }
  /* USER CODE END 3 */
}

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
/* USER CODE BEGIN 4 */
void HAL_UART_RxCpltCallback(UART_HandleTypeDef *huart)
{
	if (huart->Instance == USART3) {
		if (rx_byte == '\n' || rx_byte == '\r') {
			rx_buffer[rx_index] = 0;	/* zakończ string */
			parse_command(rx_buffer);
			rx_index = 0;
		} else if (rx_index < 49) {	/* ochrona przed przepełnieniem bufora */
			rx_buffer[rx_index++] = rx_byte;
		}
		/* RX IT trzeba zbroić ponownie po każdym bajcie. */
		HAL_UART_Receive_IT(&huart3, &rx_byte, 1);
	}
}
/* USER CODE END 4 */



 /* MPU Configuration */

void MPU_Config(void)
{
  MPU_Region_InitTypeDef MPU_InitStruct = {0};

  /* Disables the MPU */
  HAL_MPU_Disable();

  /** Initializes and configures the Region and the memory to be protected
  */
  MPU_InitStruct.Enable = MPU_REGION_ENABLE;
  MPU_InitStruct.Number = MPU_REGION_NUMBER0;
  MPU_InitStruct.BaseAddress = 0x0;
  MPU_InitStruct.Size = MPU_REGION_SIZE_4GB;
  MPU_InitStruct.SubRegionDisable = 0x87;
  MPU_InitStruct.TypeExtField = MPU_TEX_LEVEL0;
  MPU_InitStruct.AccessPermission = MPU_REGION_NO_ACCESS;
  MPU_InitStruct.DisableExec = MPU_INSTRUCTION_ACCESS_DISABLE;
  MPU_InitStruct.IsShareable = MPU_ACCESS_SHAREABLE;
  MPU_InitStruct.IsCacheable = MPU_ACCESS_NOT_CACHEABLE;
  MPU_InitStruct.IsBufferable = MPU_ACCESS_NOT_BUFFERABLE;

  HAL_MPU_ConfigRegion(&MPU_InitStruct);
  /* Enables the MPU */
  HAL_MPU_Enable(MPU_PRIVILEGED_DEFAULT);

}

/**
  * @brief  This function is executed in case of error occurrence.
  * @retval None
  */
void Error_Handler(void)
{
  /* USER CODE BEGIN Error_Handler_Debug */
  /* User can add his own implementation to report the HAL error return state */
  __disable_irq();
  while (1)
  {
  }
  /* USER CODE END Error_Handler_Debug */
}

#ifdef  USE_FULL_ASSERT
/**
  * @brief  Reports the name of the source file and the source line number
  *         where the assert_param error has occurred.
  * @param  file: pointer to the source file name
  * @param  line: assert_param error line source number
  * @retval None
  */
void assert_failed(uint8_t *file, uint32_t line)
{
  /* USER CODE BEGIN 6 */
  /* User can add his own implementation to report the file name and line number,
     ex: printf("Wrong parameters value: file %s on line %d\r\n", file, line) */
  /* USER CODE END 6 */
}
#endif /* USE_FULL_ASSERT */

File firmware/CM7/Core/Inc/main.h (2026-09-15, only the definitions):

#define BIN1_B_Pin GPIO_PIN_3
#define BIN1_B_GPIO_Port GPIOE
#define BIN2_B_Pin GPIO_PIN_4
#define BIN2_B_GPIO_Port GPIOE
#define AIN1_B_Pin GPIO_PIN_5
#define AIN1_B_GPIO_Port GPIOE
#define AIN2_B_Pin GPIO_PIN_6
#define AIN2_B_GPIO_Port GPIOE
#define SLEEP_RB_Pin GPIO_PIN_10
#define SLEEP_RB_GPIO_Port GPIOD
#define STEP_LB_Pin GPIO_PIN_6
#define STEP_LB_GPIO_Port GPIOG
#define DIR_LB_Pin GPIO_PIN_7
#define DIR_LB_GPIO_Port GPIOG
#define SLEEP_LB_Pin GPIO_PIN_8
#define SLEEP_LB_GPIO_Port GPIOG
#define STEP_RF_Pin GPIO_PIN_8
#define STEP_RF_GPIO_Port GPIOC
#define DIR_RF_Pin GPIO_PIN_9
#define DIR_RF_GPIO_Port GPIOC
#define STEP_LF_Pin GPIO_PIN_10
#define STEP_LF_GPIO_Port GPIOC
#define DIR_LF_Pin GPIO_PIN_11
#define DIR_LF_GPIO_Port GPIOC
#define DIR_RB_Pin GPIO_PIN_1
#define DIR_RB_GPIO_Port GPIOD
#define BIN1_F_Pin GPIO_PIN_10
#define BIN1_F_GPIO_Port GPIOG
#define BIN2_F_Pin GPIO_PIN_11
#define BIN2_F_GPIO_Port GPIOG
#define AIN1_F_Pin GPIO_PIN_12
#define AIN1_F_GPIO_Port GPIOG
#define AIN2_F_Pin GPIO_PIN_13
#define AIN2_F_GPIO_Port GPIOG
#define STEP_RB_Pin GPIO_PIN_14
#define STEP_RB_GPIO_Port GPIOG
#define SLEEP_RF_Pin GPIO_PIN_8
#define SLEEP_RF_GPIO_Port GPIOB
#define SLEEP_LF_Pin GPIO_PIN_9
#define SLEEP_LF_GPIO_Port GPIOB

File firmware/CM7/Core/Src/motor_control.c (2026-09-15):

#include "motor_control.h"

extern TIM_HandleTypeDef htim1;	/* PWM wspólny dla czterech mostków H */

/*
 * pin_a / pin_b — para DIR mostka H.
 * velocity == 0  → oba DIR = 0, PWM wyłączony (silnik wolny / hamowanie pasywne).
 * velocity > 0   → jazda „do przodu”, compare = velocity.
 * velocity < 0   → odwrotny DIR, compare = |velocity|.
 */
static void set_hbridge(GPIO_TypeDef *port, uint16_t pin_a, uint16_t pin_b,
			TIM_HandleTypeDef *htim, uint32_t channel, int velocity)
{
	if (velocity == 0) {
		HAL_GPIO_WritePin(port, pin_a, GPIO_PIN_RESET);
		HAL_GPIO_WritePin(port, pin_b, GPIO_PIN_RESET);
		HAL_TIM_PWM_Stop(htim, channel);
		return;
	}

	HAL_TIM_PWM_Start(htim, channel);
	if (velocity > 0) {
		HAL_GPIO_WritePin(port, pin_a, GPIO_PIN_SET);
		HAL_GPIO_WritePin(port, pin_b, GPIO_PIN_RESET);
		__HAL_TIM_SetCompare(htim, channel, velocity);
	} else {
		HAL_GPIO_WritePin(port, pin_a, GPIO_PIN_RESET);
		HAL_GPIO_WritePin(port, pin_b, GPIO_PIN_SET);
		__HAL_TIM_SetCompare(htim, channel, -velocity);
	}
}

void fright_motor(int velocity)
{
	set_hbridge(GPIOG, GPIO_PIN_12, GPIO_PIN_13, &htim1, TIM_CHANNEL_2, velocity);
}

void bright_motor(int velocity)
{
	set_hbridge(GPIOG, GPIO_PIN_10, GPIO_PIN_11, &htim1, TIM_CHANNEL_3, velocity);
}

void fleft_motor(int velocity)
{
	/* Lewa burta ma odwrotną polaryzację mostka względem prawej. */
	set_hbridge(GPIOE, GPIO_PIN_6, GPIO_PIN_5, &htim1, TIM_CHANNEL_4, velocity);
}

void bleft_motor(int velocity)
{
	set_hbridge(GPIOE, GPIO_PIN_4, GPIO_PIN_3, &htim1, TIM_CHANNEL_1, velocity);
}

void stepper_control(uint8_t enabled, GPIO_TypeDef *port, uint16_t pin, uint8_t dir_state,
		     TIM_HandleTypeDef *htim, GPIO_TypeDef *sleep_port, uint16_t sleep_pin)
{
	HAL_GPIO_WritePin(sleep_port, sleep_pin, enabled ? GPIO_PIN_SET : GPIO_PIN_RESET);
	if (enabled) {
		HAL_GPIO_WritePin(port, pin, dir_state ? GPIO_PIN_SET : GPIO_PIN_RESET);
		HAL_TIM_Base_Start_IT(htim);	/* przerwania generują impulsy STEP */
	} else {
		HAL_TIM_Base_Stop_IT(htim);
	}
}

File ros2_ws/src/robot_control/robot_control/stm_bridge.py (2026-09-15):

#!/usr/bin/env python3
"""Bridge /joy commands to the STM32 UART protocol and republish telemetry."""

import time

import rclpy
from rclpy.node import Node
from rclpy.qos import HistoryPolicy, QoSProfile, ReliabilityPolicy
from sensor_msgs.msg import Joy
from std_msgs.msg import String
import serial


class StmBridge(Node):
    def __init__(self):
        super().__init__('stm_bridge')
        self.declare_parameter('port', '/dev/ttyACM0')
        self.declare_parameter('baudrate', 115200)

        self.port_name = self.get_parameter('port').get_parameter_value().string_value
        self.baud_rate = self.get_parameter('baudrate').get_parameter_value().integer_value
        self.ser = None

        self.telemetry_pub = self.create_publisher(String, '/telemetry', 10)
        # Pad publikuje Best Effort — mostek musi mieć ten sam QoS, inaczej nie złapie /joy.
        qos = QoSProfile(
            reliability=ReliabilityPolicy.BEST_EFFORT,
            history=HistoryPolicy.KEEP_LAST,
            depth=10,
        )
        self.create_subscription(Joy, 'joy', self.joy_callback, qos)
        self.create_timer(1.0, self.ensure_connection)  # ponowne otwarcie USB po resecie Nucleo
        self.create_timer(0.01, self.read_uart)         # odczyt telemetrii ze STM32


        self.prev_lspeed = 0
        self.prev_rspeed = 0
        self.prev_hat_y = 0.0
        self.prev_btn_x = 0
        self.prev_btn_circle = 0
        self.prev_btn_triangle = 0
        self.prev_btn_square = 0

        self.get_logger().info(f'STM bridge starting on {self.port_name} @ {self.baud_rate}')
        self.connect()

    def connect(self):
        if self.ser and self.ser.is_open:
            return True
        try:
            self.ser = serial.Serial(self.port_name, self.baud_rate, timeout=0.1)
            self.get_logger().info(f'Opened {self.port_name}')
            # DTR przy otwarciu portu resetuje STM32 — czekamy, aż wróci boot.
            time.sleep(1.0)
            for _ in range(3):
                self.send_command('ready')
                time.sleep(0.5)
            return True
        except Exception as exc:
            self.get_logger().error(f'UART open failed: {exc}')
            return False

    def ensure_connection(self):
        if self.ser is None or not self.ser.is_open:
            self.connect()

    def read_uart(self):
        if not (self.ser and self.ser.is_open):
            return
        try:
            if self.ser.in_waiting <= 0:
                return
            line = self.ser.readline().decode('utf-8', errors='ignore').strip()
            if not line:
                return
            msg = String()
            # Dopinamy aktualne zadanie z pada, bo telemetria STM ma tylko RPM kół.
            msg.data = f'{line}, {self.prev_lspeed}, {self.prev_rspeed}'
            self.telemetry_pub.publish(msg)
        except Exception:
            pass

    @staticmethod
    def map_analog_to_speed(raw_value):
        try:
            val = int(float(raw_value))
        except (TypeError, ValueError):
            return 0
        if 115 <= val <= 140:
            return 0  # martwa strefa środka gałki (osie przychodzą jako 0…255)
        speed = int((val - 127) * 0.78)  # 0…255 → ok. −100…100
        return max(-100, min(100, speed))

    def joy_callback(self, msg):
        try:
            if len(msg.axes) > 5:
                # axes[1] / axes[5] = lewy i prawy analog; * -1 bo gałka do przodu
                # dawała ujemną prędkość względem kierunku jazdy robota.
                left = self.map_analog_to_speed(msg.axes[1]) * -1
                right = self.map_analog_to_speed(msg.axes[5]) * -1
                if left != self.prev_lspeed:
                    self.send_command(f'lspeed={left}')
                    self.prev_lspeed = left
                if right != self.prev_rspeed:
                    self.send_command(f'rspeed={right}')
                    self.prev_rspeed = right

            if len(msg.buttons) >= 4:
                # Zbocze 0→1, żeby jedno wciśnięcie przełączało silnik krokowy.
                if msg.buttons[0] == 1 and self.prev_btn_x == 0:
                    self.send_command('bleft_step')
                self.prev_btn_x = msg.buttons[0]
                if msg.buttons[3] == 1 and self.prev_btn_square == 0:
                    self.send_command('bright_step')
                self.prev_btn_square = msg.buttons[3]
                if msg.buttons[2] == 1 and self.prev_btn_triangle == 0:
                    self.send_command('fleft_step')
                self.prev_btn_triangle = msg.buttons[2]
                if msg.buttons[1] == 1 and self.prev_btn_circle == 0:
                    self.send_command('fright_step')
                self.prev_btn_circle = msg.buttons[1]

            if len(msg.axes) > 7:
                hat = msg.axes[7]  # D-pad góra/dół
                if hat != self.prev_hat_y:
                    if hat == 1.0:
                        self.send_command('forward')
                    elif hat == -1.0:
                        self.send_command('backward')
                    elif hat == 0.0:
                        self.send_command('stop')
                    self.prev_hat_y = hat
        except Exception as exc:
            self.get_logger().error(f'Joy callback failed: {exc}')

    def send_command(self, command):
        if not (self.ser and self.ser.is_open):
            return
        try:
            self.ser.write((command + '\n').encode('utf-8'))
        except Exception as exc:
            self.get_logger().error(f'UART write failed: {exc}')

    def destroy_node(self):
        if self.ser and self.ser.is_open:
            self.ser.close()
        super().destroy_node()


def main(args=None):
    rclpy.init(args=args)
    node = StmBridge()
    try:
        rclpy.spin(node)
    except KeyboardInterrupt:
        pass
    finally:
        node.destroy_node()
        if rclpy.ok():
            rclpy.shutdown()


if __name__ == '__main__':
    main()

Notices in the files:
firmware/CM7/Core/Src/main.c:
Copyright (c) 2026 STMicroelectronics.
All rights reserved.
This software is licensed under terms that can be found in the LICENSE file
